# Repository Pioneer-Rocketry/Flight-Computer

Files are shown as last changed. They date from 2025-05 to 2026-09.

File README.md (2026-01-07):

# Pioneer Rocketry Flight Computer

Pioneer Rocketry’s latest generation flight computer for high power, STM32-based avionics system designed for experimental high-power rockets. It provides state estimation, real-time telemetry, staging logic, and fully active control capabilities.
This repository contains the firmware, test tools, and documentation for the system.

---

## Prerequisites

Before building this project, ensure you have the following tools installed and added to your system `PATH`:

1.  **[Visual Studio Code](https://code.visualstudio.com/)** or **[STM32CubeIDE](https://www.st.com/en/development-tools/stm32cubeide.html#get-software)**
2.  **[STM32CubeMX](https://www.st.com/en/development-tools/stm32cubemx.html)** (v6.13 or newer) - Required to generate hardware config.
3.  **Make** Use `winget install ezwinports.make` or `choco install make` - Build system generator.
4.  **[Arm GNU Toolchain](https://developer.arm.com/downloads/-/arm-gnu-toolchain-downloads)** - The compiler (e.g., `arm-none-eabi-gcc`).
5.  **[Ninja Build](https://github.com/ninja-build/ninja/releases)** (Optional) - A faster build system than Make.

### VS Code Extensions
Install the following extensions within VS Code:
* **[Cortex Debug](https://marketplace.visualstudio.com/items?itemName=marus25.cortex-debug)**

---

## Build Instructions

### 1. Clone and Open
Clone the repository and open the folder in VS Code:
```bash
git clone --recurse-submodules https://github.com/Pioneer-Rocketry/Flight-Computer.git
```
### 2. Build the Firmware

You can build the project using the status bar at the bottom or the Command Palette:

* **Status Bar:** Click **Build** (or the generic "Gear" icon).
* **Shortcut:** Press `F7`.

*Successful build output will create a `Code.elf` and `Code.bin` file in the `./Code/build/` directory.*

### 3. Flash and Debug

Connect your STM32 board via ST-Link.

1. Press `F5` to start debugging.
2. The extension will automatically:
* Build the latest code.
* Flash the board using OpenOCD/ST-Link.
* Open the debug console.

### Troubleshooting

* **"Multiple target patterns" error:** Ensure your project folder path contains **NO SPACES** (e.g., use `C:\Dev\Project` instead of `C:\Users\My Name\Project`).
* **C++ vs C:** If `main.cpp` is not being compiled, check `CMakeLists.txt` to ensure `CXX` is enabled and `main.cpp` is listed in the source files. If main.c is in the CDEF, remove it and delete the file.

## Hardware Overview

### **Primary Components**

| Function | Component |
|----|----|
| Main MCU | **STM32F446RE** |
| High-G IMU (Accel + Gyro) | **LSM6DSV32X** |
| Magnetometer | **MMC5603** |
| Barometer | **MS5607-02BA03** |
| GPS | **u-blox SAM-M8Q** |
| Radio | **LoRa SX1262** |

### **Additional Hardware Features**

* 3 independent **pyrotechnic deployment channels**
* Breakouts for **I²C** and **SPI** expansion
* Support for **4 servo channels** (vectoring, control surfaces, etc.)
* USB/Serial connectivity for configuration and simulation
* Ruggedized PCB designed for high-G, high-speed flight

---

## Software Overview

The firmware is written in modern **C++**, using HAL for low-level drivers and a modular class-based architecture for sensors, telemetry, and estimation modules.

### **Key Capabilities**

* **State estimation** for:
  * Attitude (roll, pitch, yaw)
  * Position (x, y, z)
  * Velocity and angular rates
    *(Uses a custom multi-sensor Kalman Filter.)*
* **Live telemetry** over LoRa
* **Event-driven flight logic**, including:
  * Ascent/descent detection
  * Apogee detection
  * Staging and separation logic
  * Deployment sequencing
* **Active Control**
  * Servo-driven stabilization or thrust-vectoring
  * Optional closed-loop controls for advanced tests
* **Fault-tolerant design**
  * Sensor redundancy
  * Fail-safe deployment rules
  * Logging of all states and events

---

## Testing Strategy

### **Hardware-in-the-Loop Testing (HILT)**

HILT allows the flight computer to run full flight software using simulated sensor data.

* The board connects to a PC via USB/Serial.
* A custom simulator streams “fake” IMU, barometer, and GPS data.
* The firmware behaves exactly as if it were in flight.
* Allows testing:
  * Sensor fusion
  * State transitions
  * Staging logic
  * Deployment logic
  * Data logging and telemetry

This framework accelerates development and eliminates many failure modes before field testing.

---

### **Field & Flight Testing**

Flight testing follows a staged, risk-managed approach:

1. **Initial flights:** Validate basic state estimation (position, velocity, attitude) and state transitions.
2. **Intermediate flights:** Add automated apogee deployment, then drogue/main testing, then multistage events.
3. **Advanced flights:**
   * High-speed, high-G tests
   * Full staging logic
   * Active control (servo-active fins or TVC)
   * Redundancy and fault recovery tests

Each successful flight unlocks the next feature set, ensuring safe and repeatable progress toward fully active control.

---

## Repository Structure

```
Flight-Computer/
├── Code/
│   ├── Core/
│   │   ├──Src/
│   │   └── Inc/
│   └── lib/
├── Datasheets/
└── PCB/
```

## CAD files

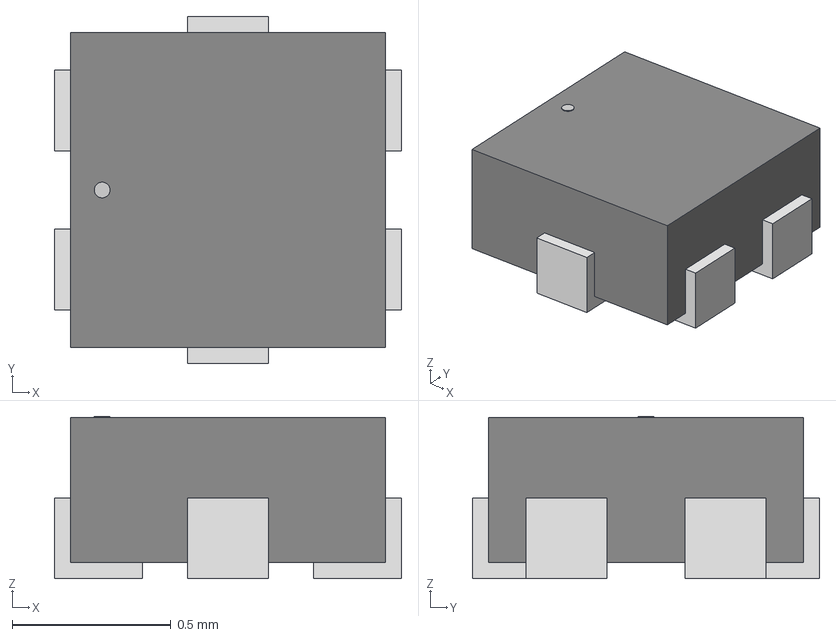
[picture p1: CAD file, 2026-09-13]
PCB/Imported Parts/QFN_453-385LF_SKY.step
1.09 x 1.09 x 0.511 mm

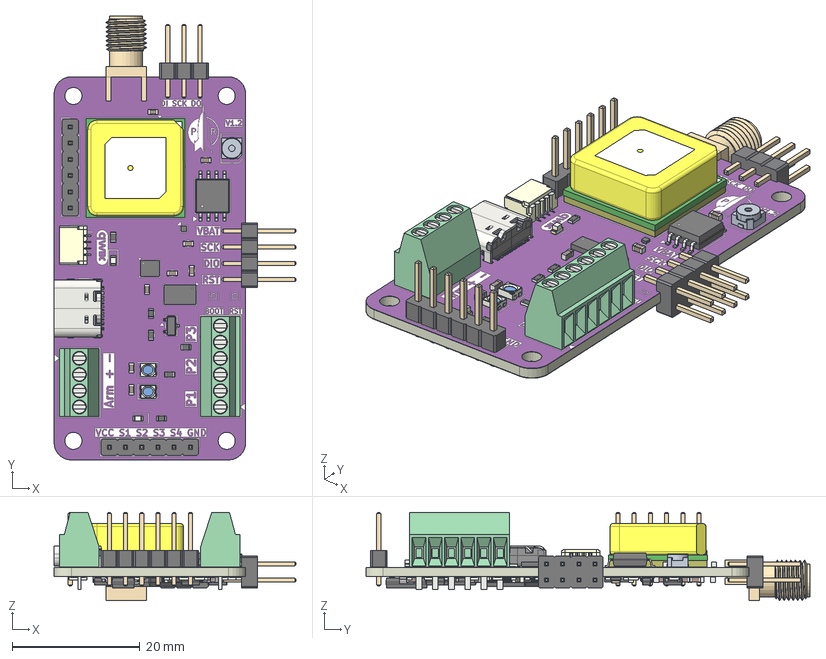
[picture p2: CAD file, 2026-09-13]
PCB/Output/Flight Computer.step
37.9 x 69.5 x 13.8 mm
LED_WS2812B-Mini_PLCC4_3.5x3.5mm_P1.8mm x 2
R_0603_1608Metric x 28
C_0603_1608Metric x 34
WLP-4_0.86x0.86mm_P0.4mm
PinHeader_1x06_P254mm_Vertical x 2
SOT-23-3 x 5
SAM-M8Q-0-10
TerminalBlock_Phoenix_MPT-0,5-4-2.54_1x04_P2.54mm_Horizontal
SM04B-SRSS-TB(LF)(SN)
PinHeader_2x04_P254mm_Vertical
USB_C_Receptacle_16P_TopMnt_Horizontal_GCT_USB4105-xx-A
TerminalBlock_Phoenix_MPT-0,5-6-2.54_1x06_P2.54mm_Horizontal
PRT0002
PRT0008
SOIC-8_5.3x5.3mm_P1.27mm
LGA_14_3x25mm_P05mm_LayoutBorder3x4y
LED_0603_1608Metric x 2
PinHeader_2x03_P254mm_Vertical
LGA_8_3x5mm_P125mm
L_0603_1608Metric x 7
SOT-23 x 2
LQFP-64_10x10mm_P0.5mm
Crystal_SMD_2016-4Pin_2.0x1.6mm
QFN-24-1EP_4x4mm_Pitch0.5mm
SOT-223
SMA_Samtec_SMA-J-P-H-ST-EM1_EdgeMount
CSTNE8M00GH5C000R0
Flight Computer_silkscreen x 2
Flight Computer_soldermask x 2
Flight Computer_PCB

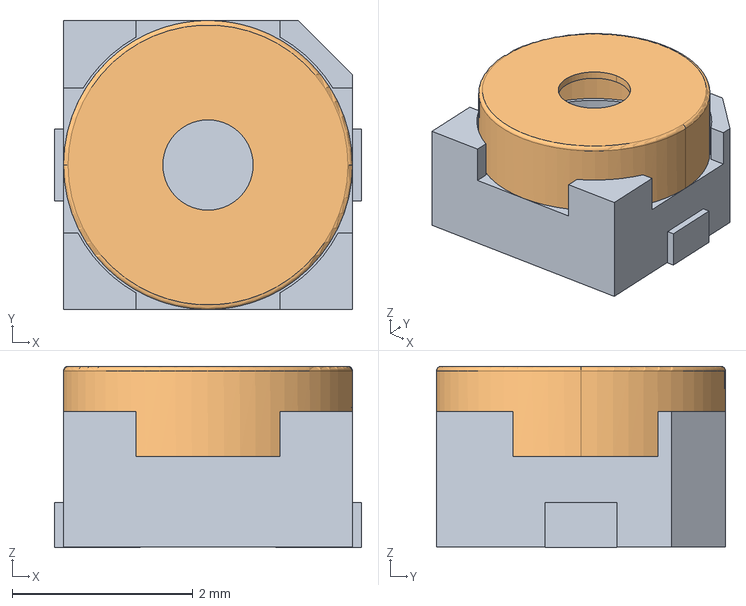
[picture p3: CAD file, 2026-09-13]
PCB/Imported Parts/CT03E-04S400-1_2-2020_062220.stp
3.40 x 3.20 x 2.01 mm
PRT0002
PRT0008

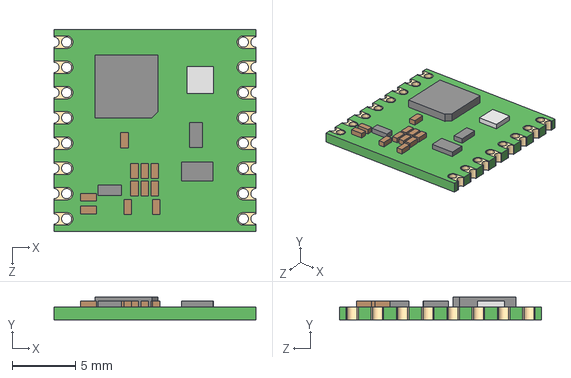
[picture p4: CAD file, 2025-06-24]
PCB/Imported Parts/RFM95W-868S2--3DModel-STEP-56544.STEP
16.0 x 1.80 x 16.0 mm

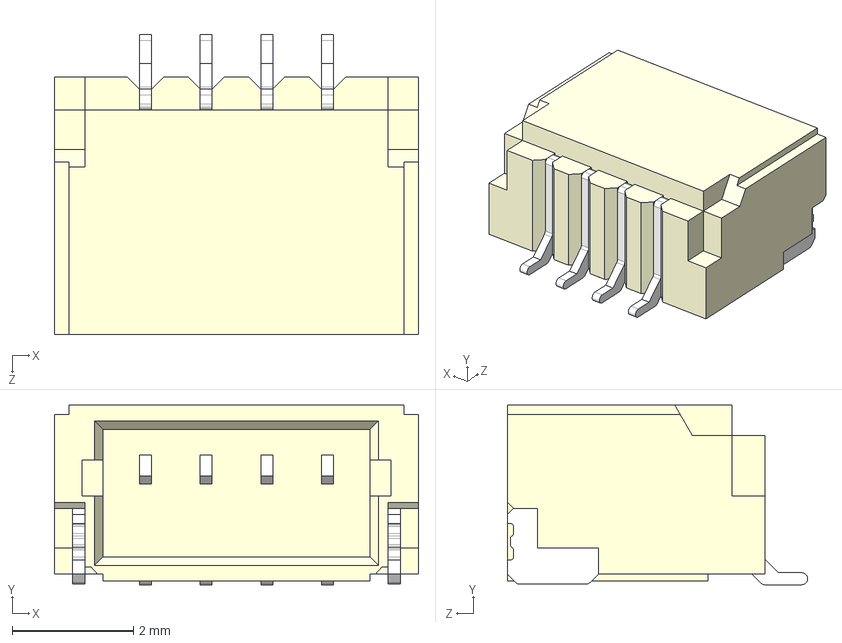
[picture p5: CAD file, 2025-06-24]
PCB/Imported Parts/SM04B-SRSS-TB.STEP
6.00 x 2.96 x 4.95 mm

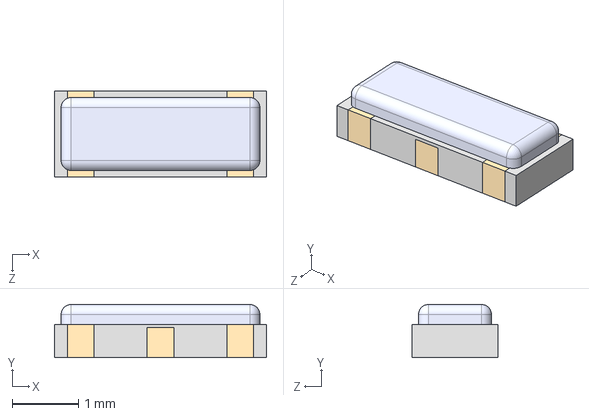
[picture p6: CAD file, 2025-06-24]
PCB/Imported Parts/CSTNE8M00G52Z000R0.STEP
3.20 x 0.8 x 1.30 mm

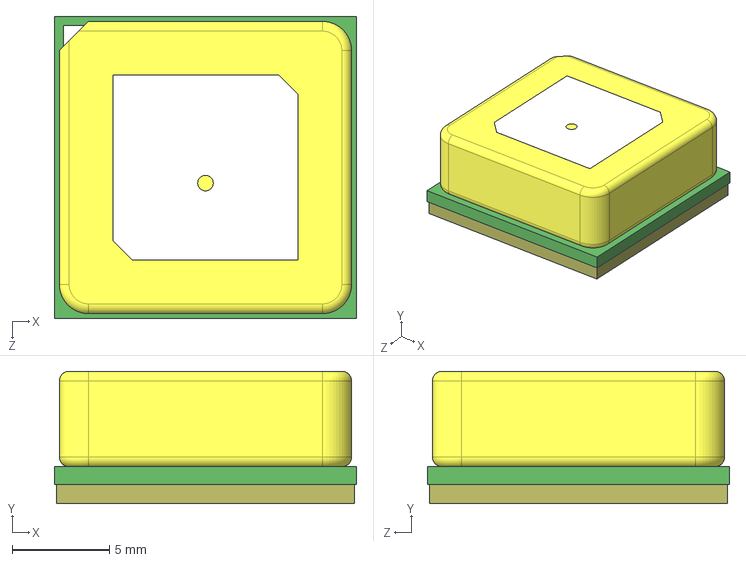
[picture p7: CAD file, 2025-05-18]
PCB/Imported Parts/SAM-M8Q-0.STEP
15.5 x 6.80 x 15.5 mm

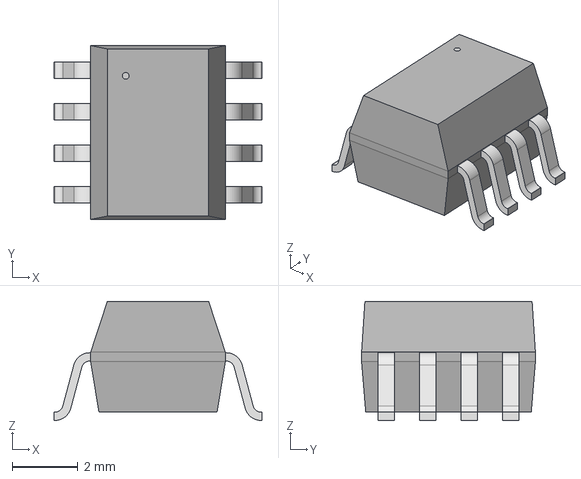
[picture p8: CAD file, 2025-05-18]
PCB/Imported Parts/SOIC-8_VOIH063A_VIS.step
6.35 x 5.31 x 3.63 mm

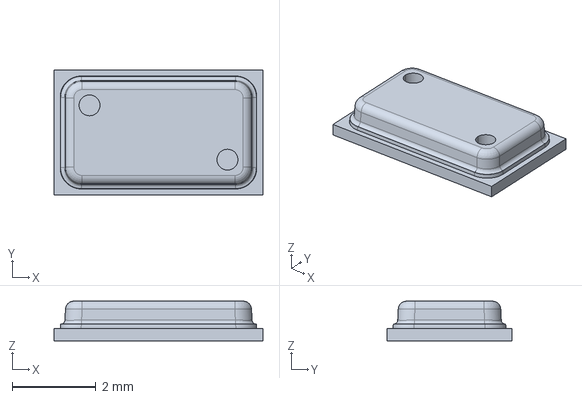
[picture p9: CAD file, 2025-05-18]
PCB/Imported Parts/MS560702BA03-50.STEP
5.00 x 3.00 x 0.95 mm

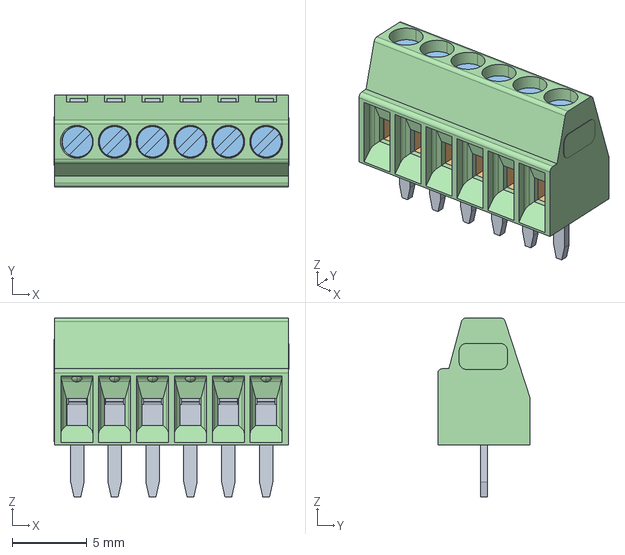
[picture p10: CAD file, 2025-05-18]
PCB/Imported Parts/screw terminal.stp
15.8 x 6.20 x 12.0 mm

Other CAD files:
PCB/Imported Parts/SKY13453.step

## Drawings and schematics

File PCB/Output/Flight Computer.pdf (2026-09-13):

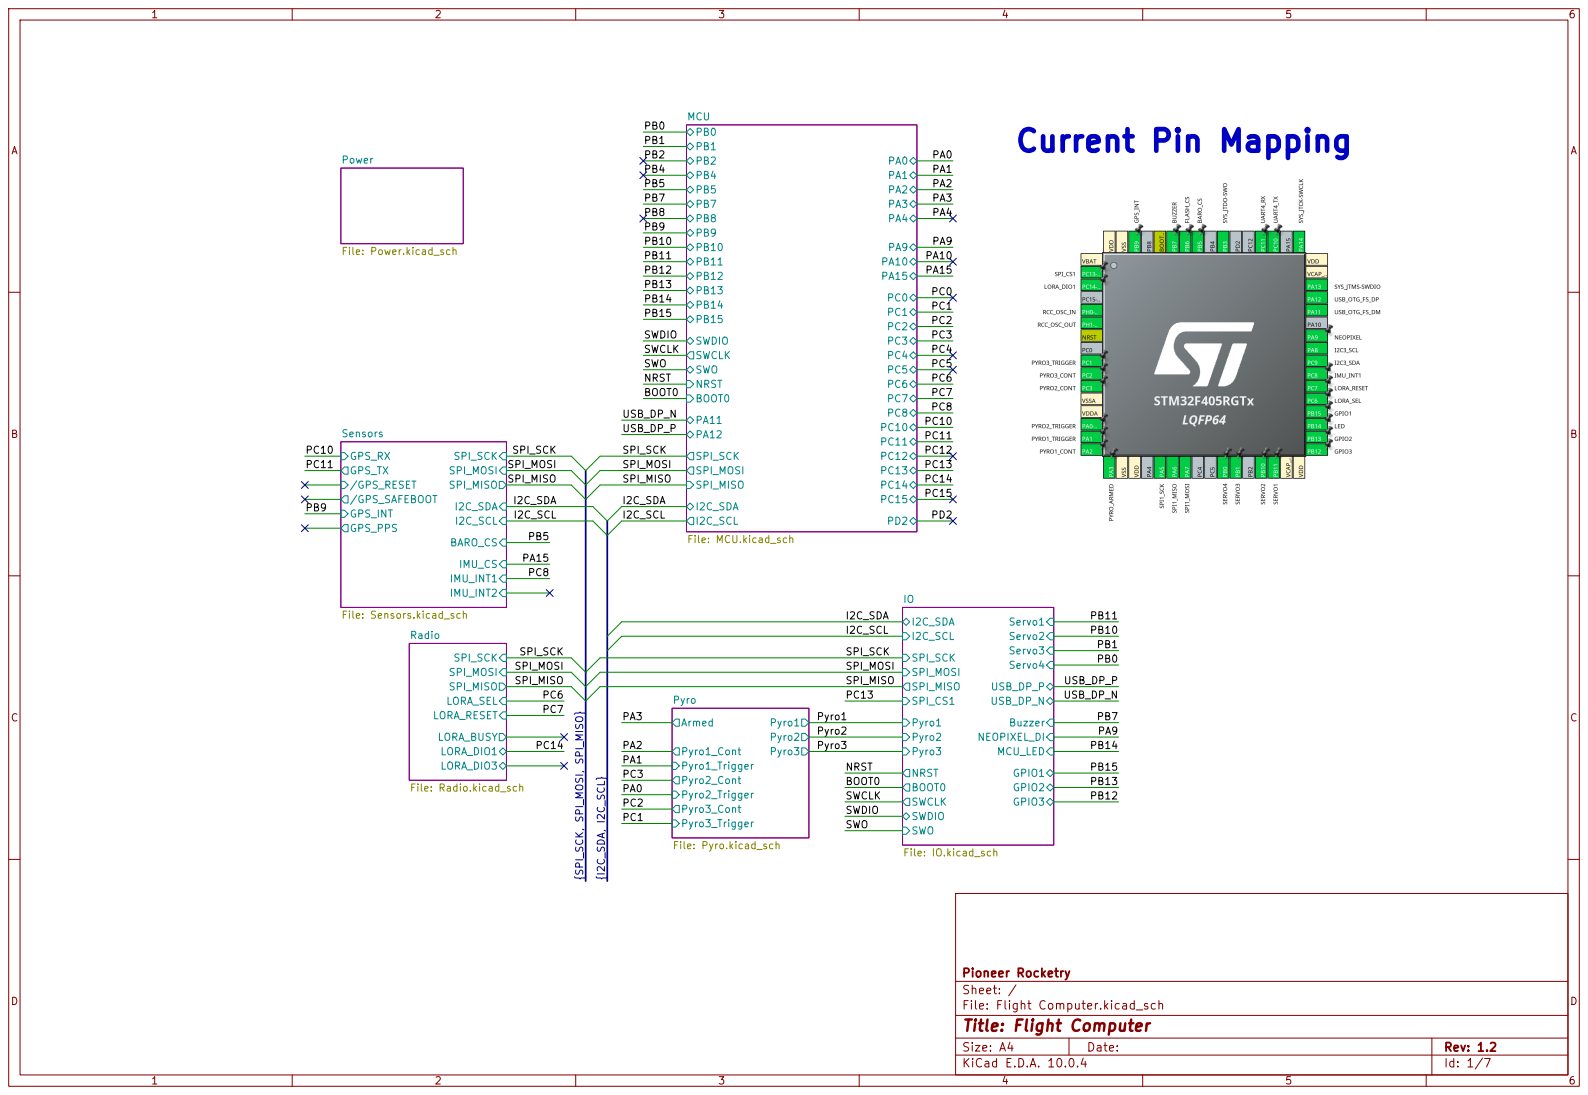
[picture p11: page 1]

File: MCU.kicad_sch Power File: Power.kicad_schSPI_SCK

Size: A4 | Rev: 1.2
KiCad E.D.A. 10.0.4 | Id: 1/7

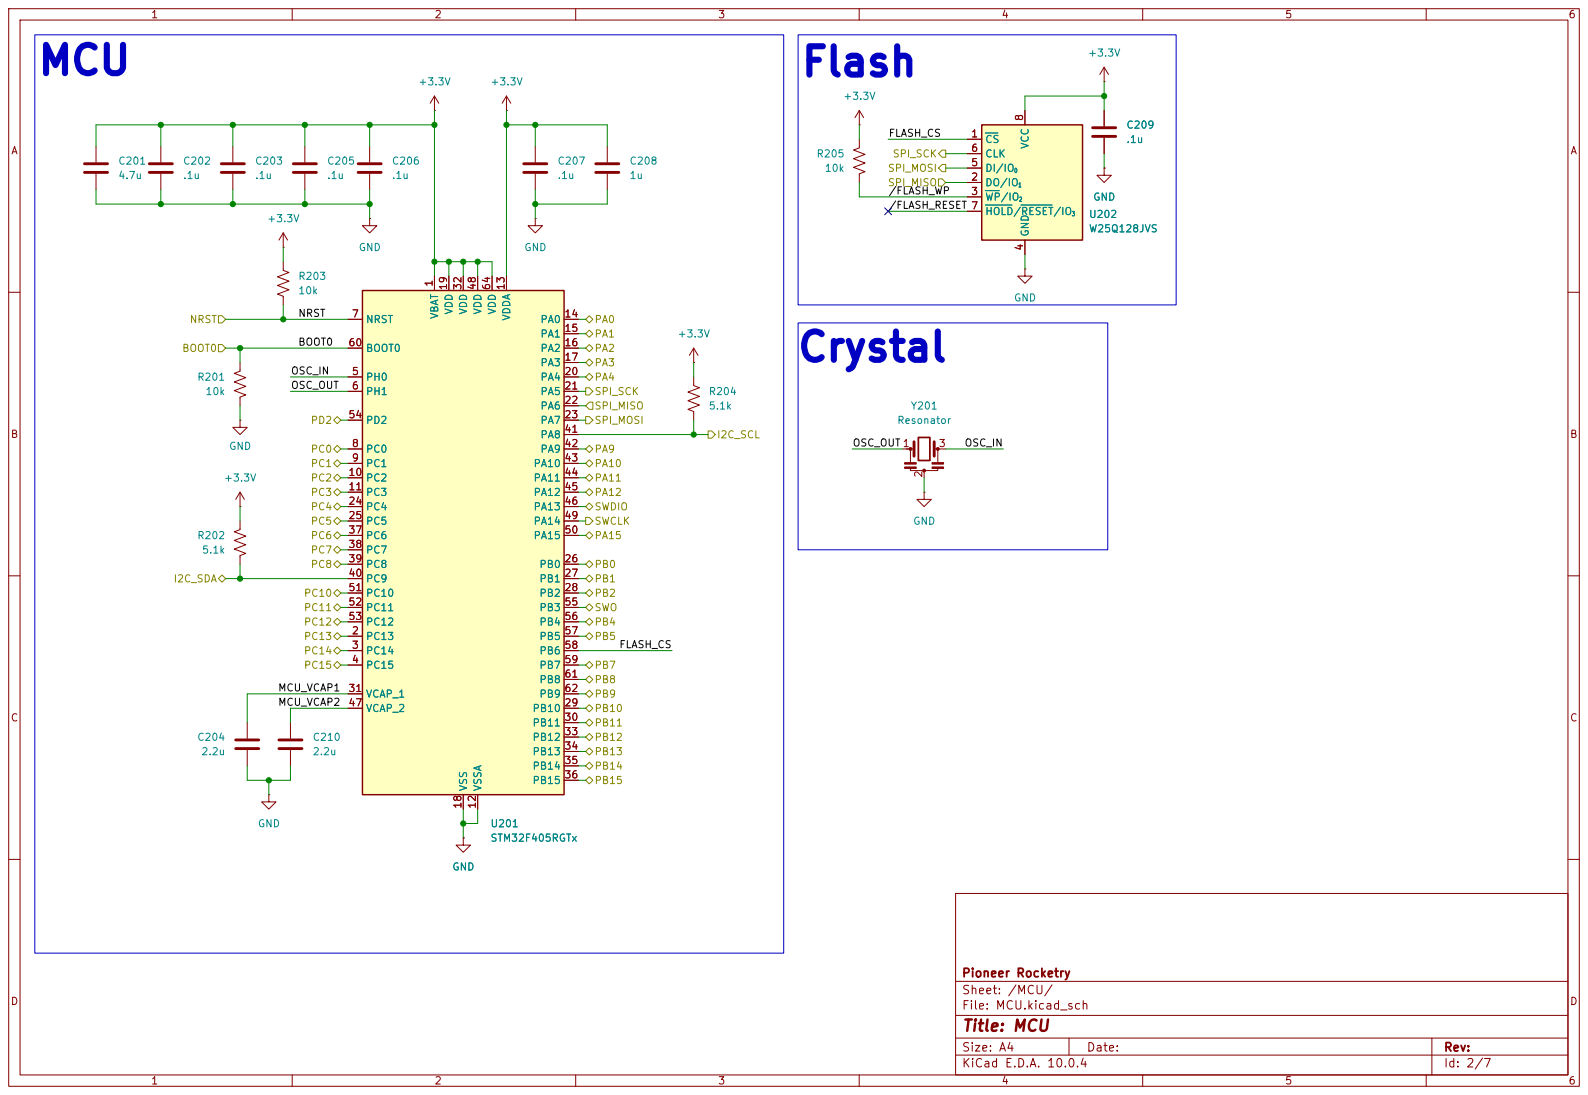
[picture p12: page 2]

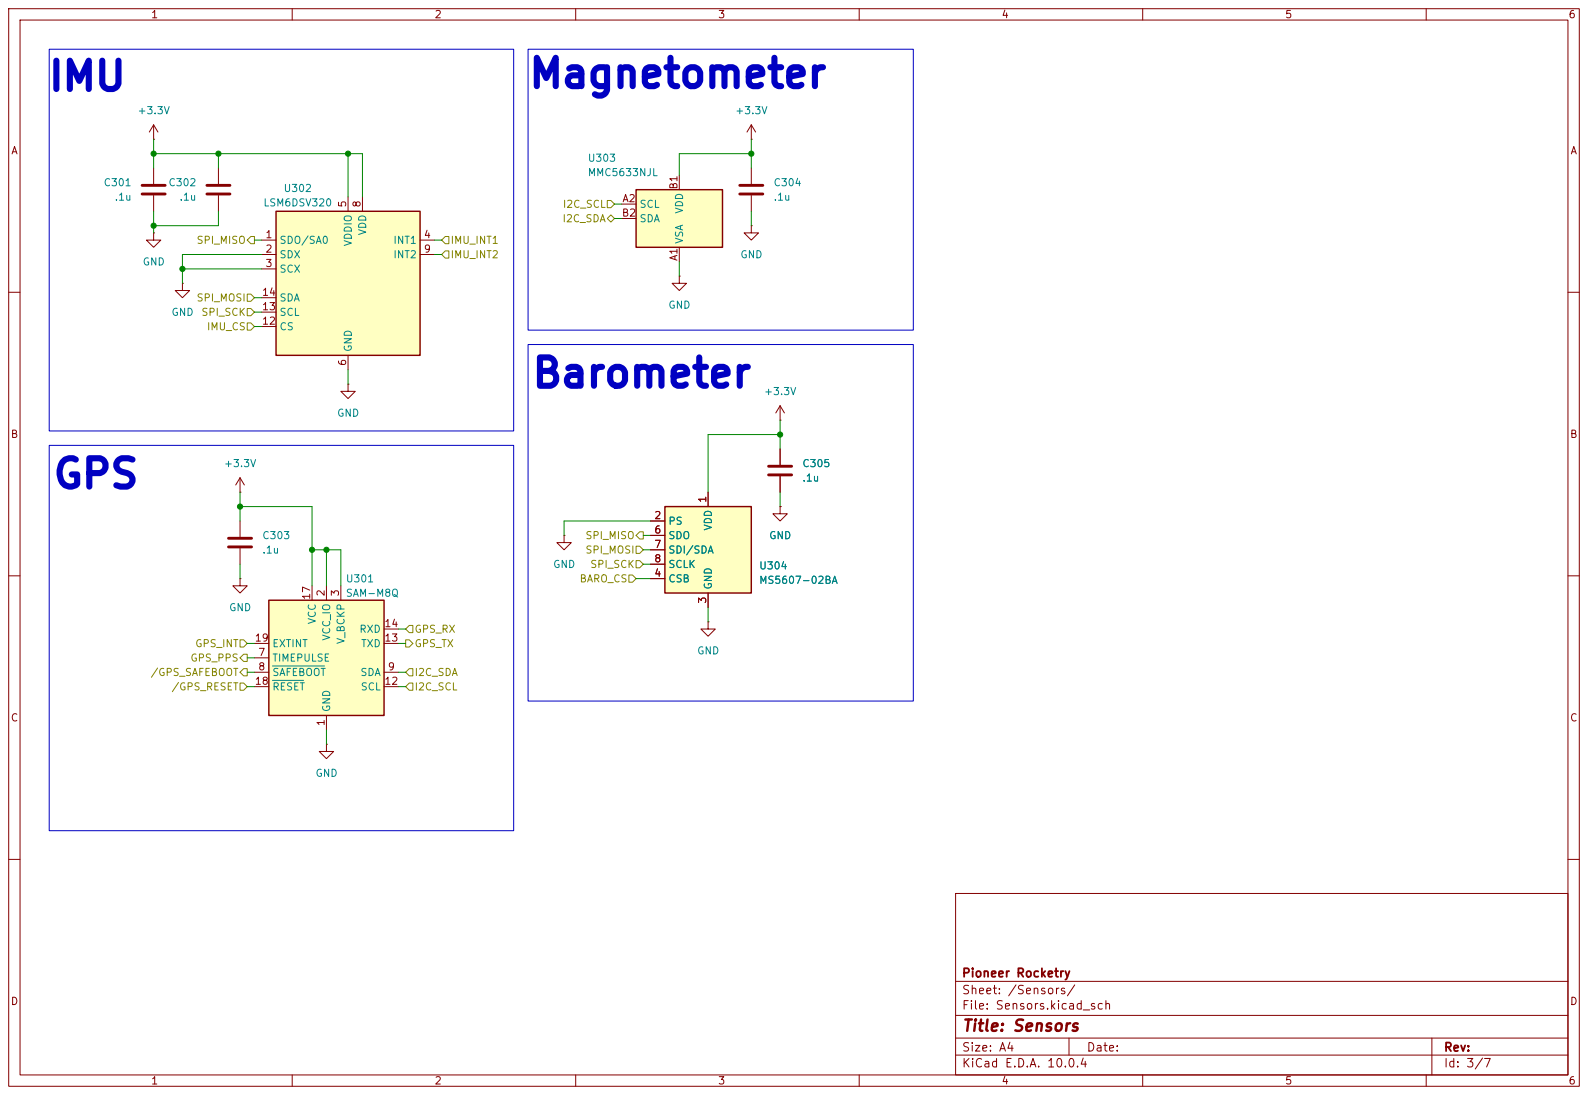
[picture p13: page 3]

TXD 13 RXD 14 VCC 17 RESET 18

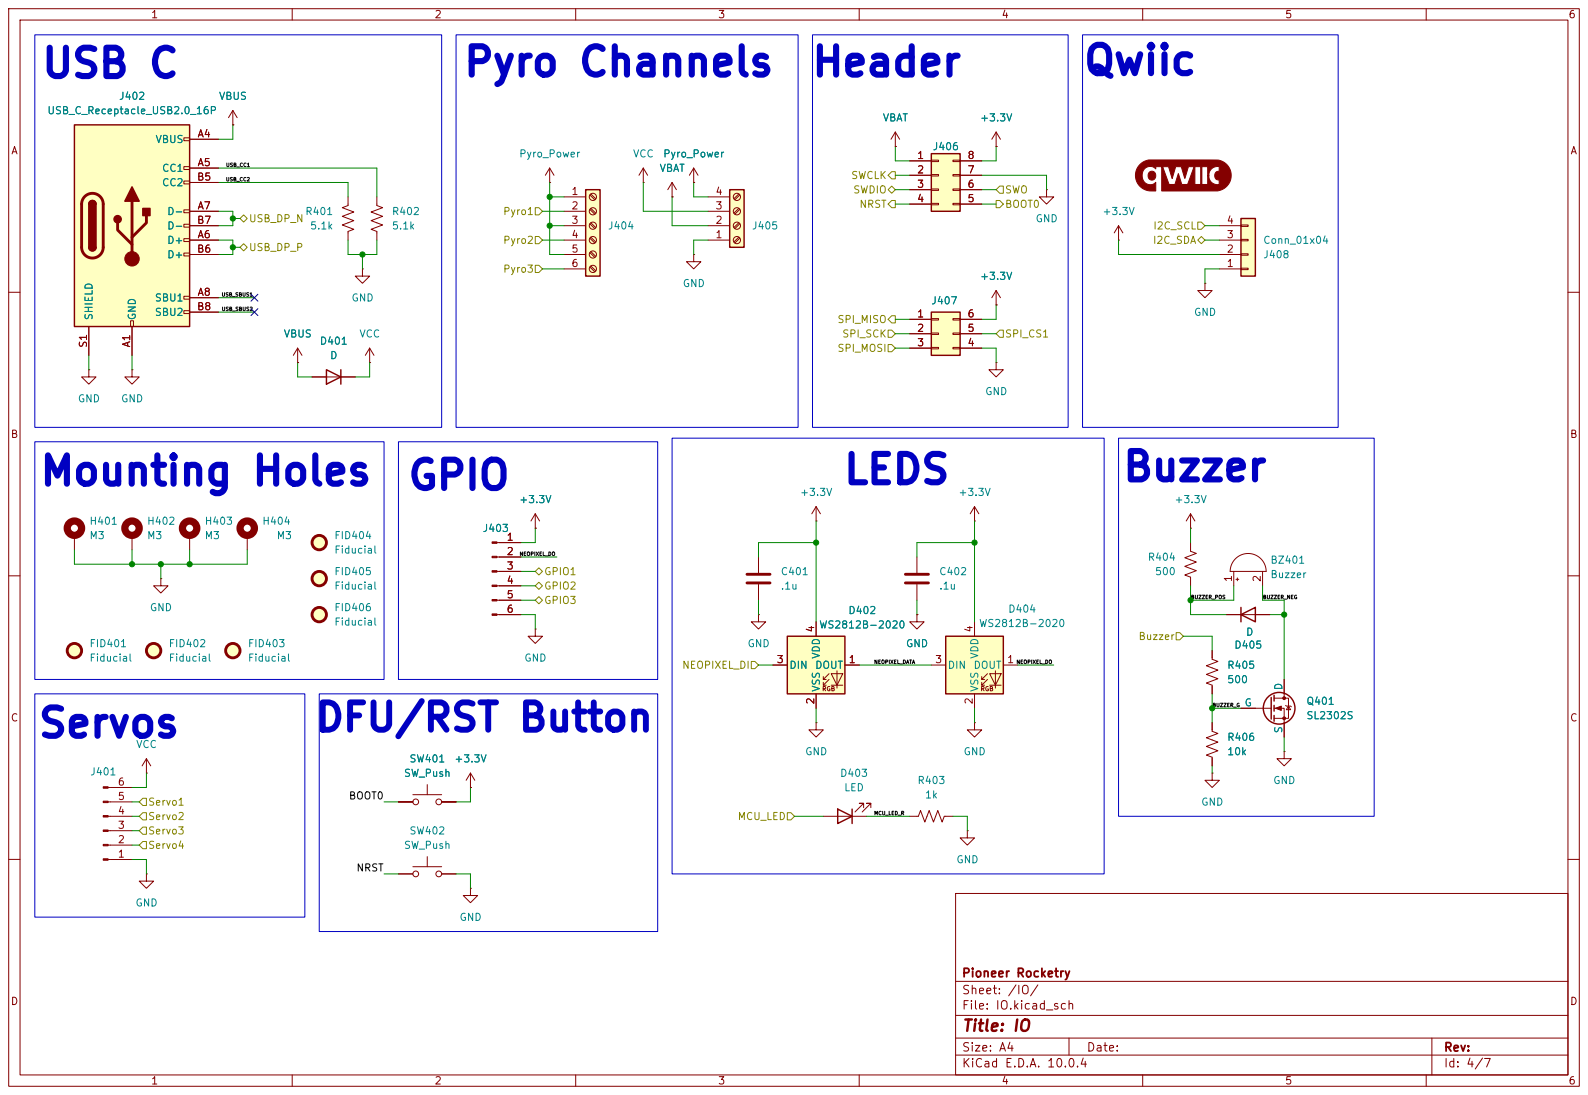
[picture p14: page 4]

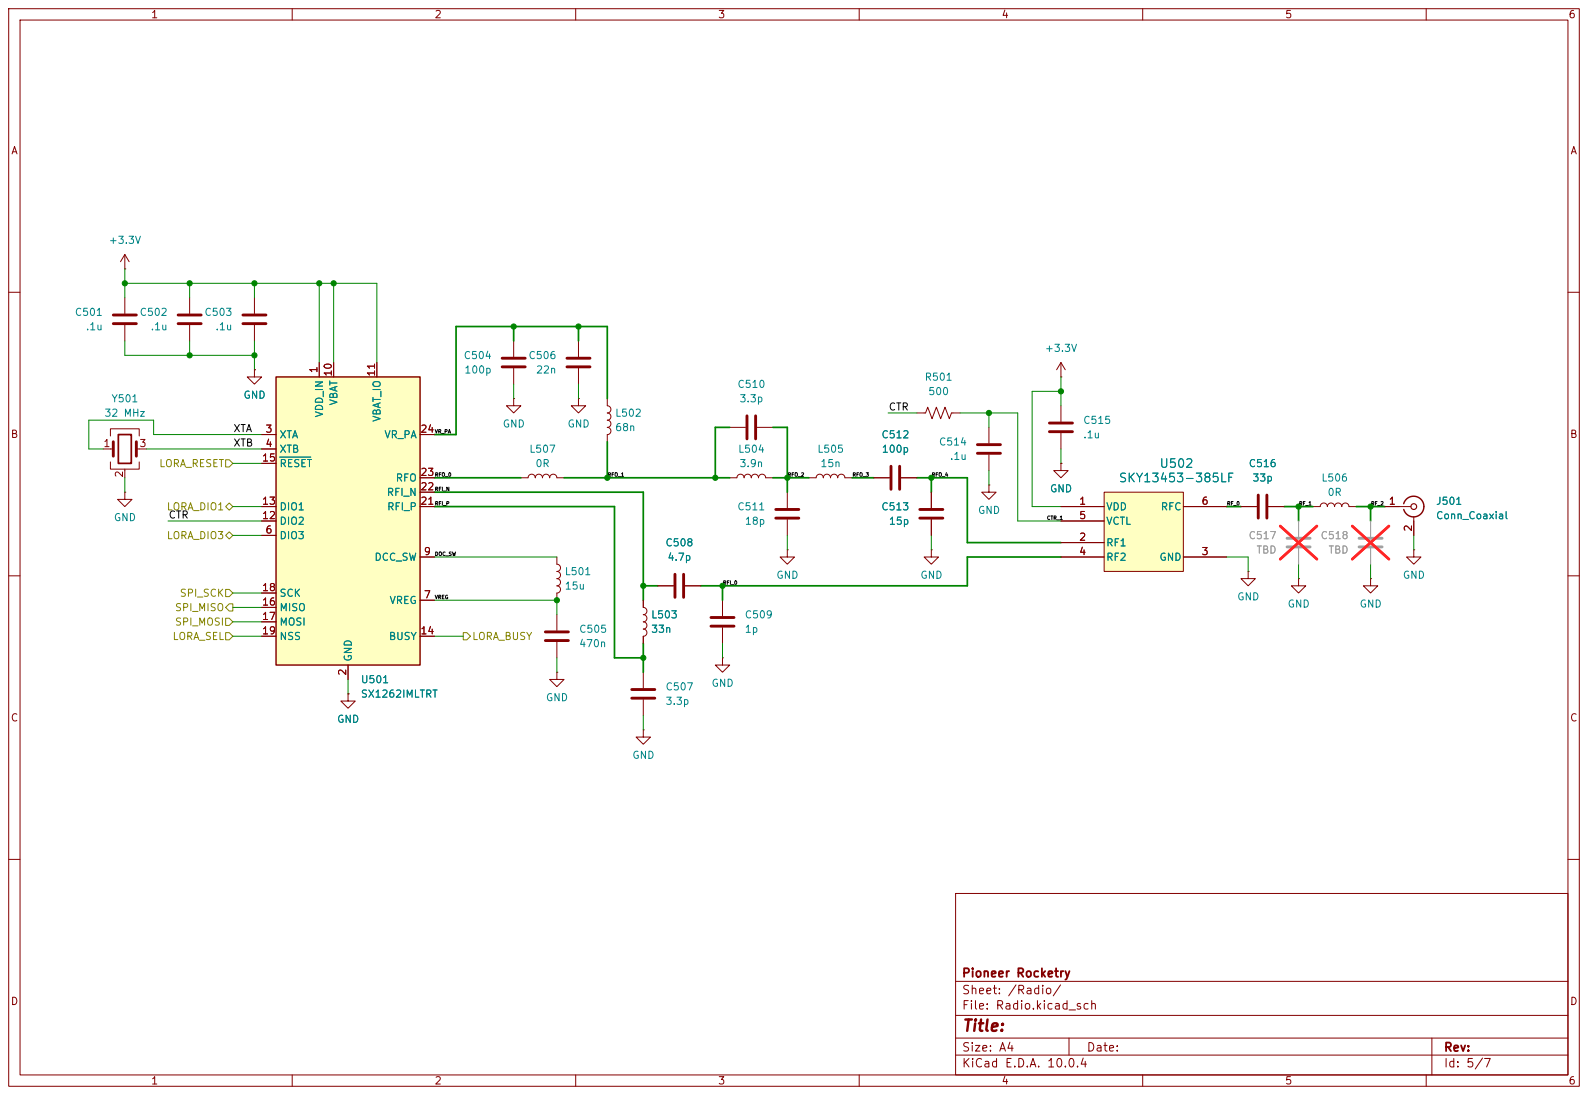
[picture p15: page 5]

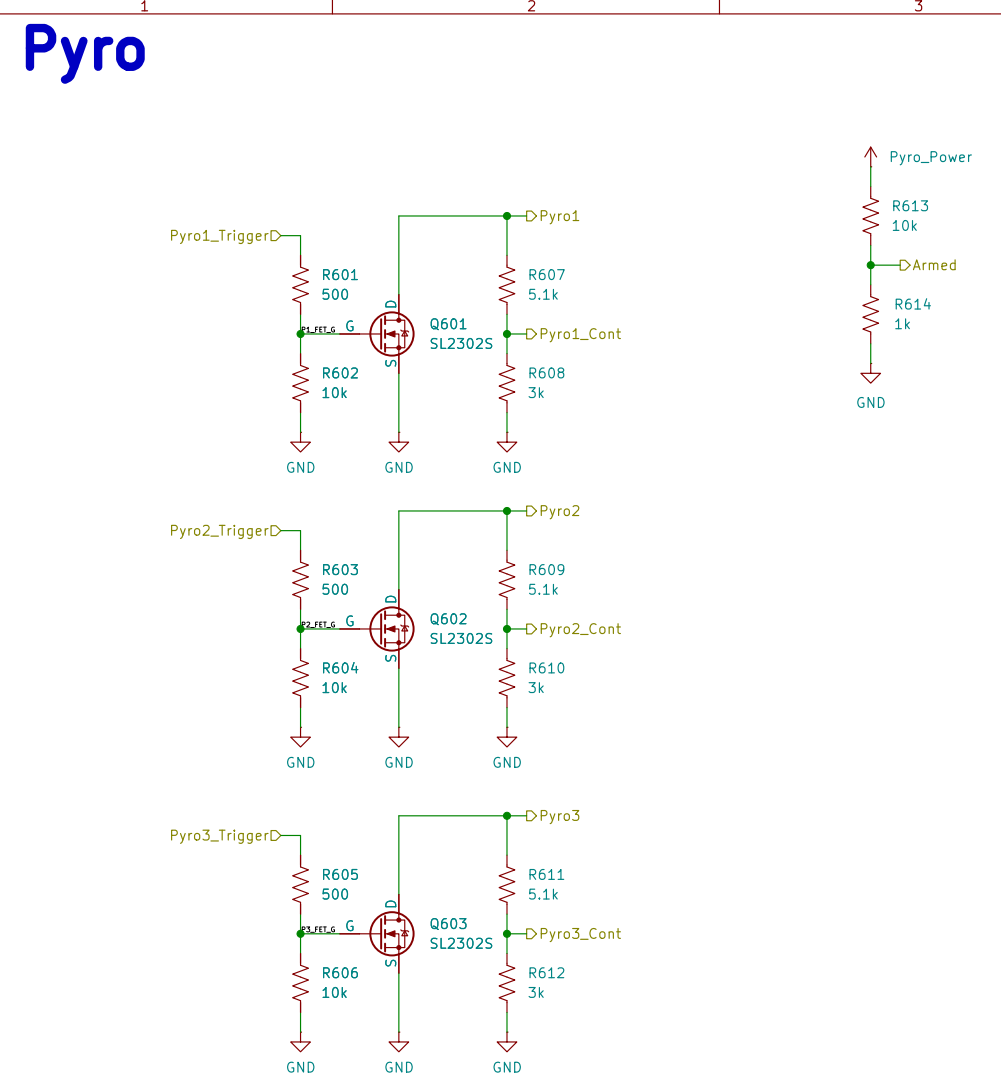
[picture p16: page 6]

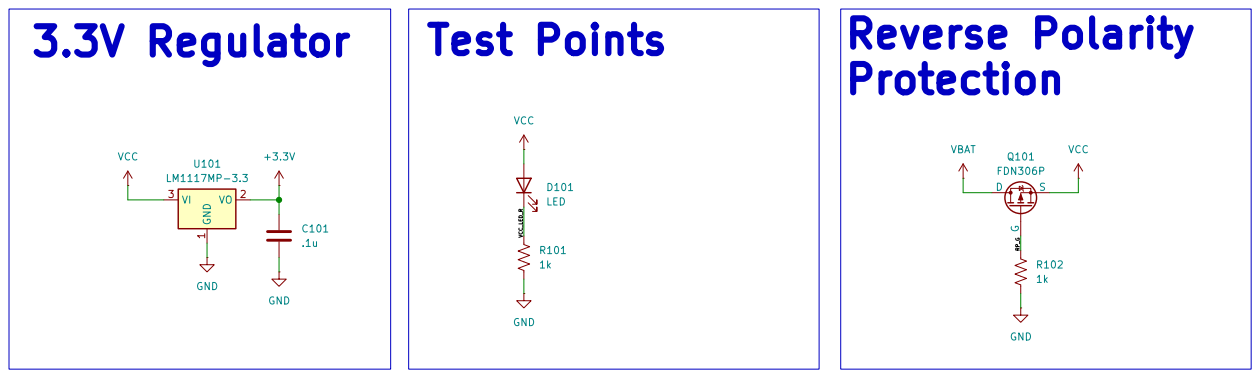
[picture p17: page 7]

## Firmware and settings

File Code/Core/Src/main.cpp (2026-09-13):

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
/* Includes ------------------------------------------------------------------*/
#include "main.h"

/* USER CODE BEGIN Includes */

#include <ctype.h>
#include "tusb.h"
#include "dfuBootloader.h"
#include "usbHelper.h"

#include "DataContainer.h"

/* USER CODE END Includes */

ADC_HandleTypeDef hadc1;

I2C_HandleTypeDef hi2c3;

SPI_HandleTypeDef hspi1;

TIM_HandleTypeDef htim1;
TIM_HandleTypeDef htim2;
TIM_HandleTypeDef htim3;
TIM_HandleTypeDef htim12;

UART_HandleTypeDef huart4;

PCD_HandleTypeDef hpcd_USB_OTG_FS;

extern "C" void SystemClock_Config(void);
static void MX_GPIO_Init(void);
static void MX_ADC1_Init(void);
static void MX_I2C3_Init(void);
static void MX_SPI1_Init(void);
static void MX_TIM1_Init(void);
static void MX_TIM2_Init(void);
static void MX_TIM3_Init(void);
static void MX_TIM12_Init(void);
static void MX_UART4_Init(void);
static void MX_USB_OTG_FS_PCD_Init(void);
/**
  * @brief  The application entry point.
  * @retval int
  */
int main(void)
{

  /* USER CODE BEGIN 1 */

  dfuCheckAndJumpBootloader();

  /* USER CODE END 1 */

  /* MCU Configuration--------------------------------------------------------*/

  /* Reset of all peripherals, Initializes the Flash interface and the Systick. */
  HAL_Init();

  /* Configure the system clock */
  SystemClock_Config();

  /* Initialize all configured peripherals */
  MX_GPIO_Init();
  MX_ADC1_Init();
  MX_I2C3_Init();
  MX_SPI1_Init();
  MX_TIM1_Init();
  MX_TIM2_Init();
  MX_TIM3_Init();
  MX_TIM12_Init();
  MX_UART4_Init();
  MX_USB_OTG_FS_PCD_Init();
  /* USER CODE BEGIN 2 */

  tud_init(BOARD_TUD_RHPORT);

  uint32_t currentTick;
  uint32_t lastSendTick = 0;
  const uint32_t sendIntervalMs = 5000;

  /* USER CODE END 2 */

  /* Infinite loop */
  /* USER CODE BEGIN WHILE */
  while (1)
  {
    /* USER CODE END WHILE */

    /* USER CODE BEGIN 3 */

    tud_task();

    currentTick = HAL_GetTick(); // Get the current system tick (ms)

    // Check if it's time to send data
    if (currentTick - lastSendTick >= sendIntervalMs)
    {
      lastSendTick = currentTick;

      int len = snprintf(usb_tx_buffer, MAX_TICK_MSG_LEN, "Tick: %lu ms\r\n", currentTick);
      cdcSendMessage(usb_tx_buffer, len);
    }
  }
  /* USER CODE END 3 */
}

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
/* USER CODE BEGIN 4 */


void tud_dfu_runtime_reboot_to_dfu_cb(void)
{
  const char* reboot_msg = "Rebooting into DFU mode...\r\n";
  cdcSendMessage(reboot_msg, strlen(reboot_msg));

  // Ensure message is sent
  for (int i = 0; i < 10; i++) {
    tud_task();
    HAL_Delay(5);
  }

  // Request bootloader entry (never returns)
  dfuRequestBootloaderEntry();

}

void tud_dfu_download_cb(uint8_t alt, uint16_t block_num, uint8_t const* data, uint16_t length)
{
  (void)alt;
  (void)block_num;
  (void)data;
  (void)length;

  // This callback is called during the download process
  // We don't need to do anything here since we're using runtime DFU
}

void tud_dfu_manifest_cb(uint8_t alt)
{
  (void)alt;

  // DFU upload complete, reboot back to application
  // Give a short delay to ensure USB transaction completes
  HAL_Delay(100);

  // System reset to return to application
  NVIC_SystemReset();
}


/* USER CODE END 4 */
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


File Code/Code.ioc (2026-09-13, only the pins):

Mcu.UserName=STM32F405RGTx
PA0-WKUP.GPIO_Label=PYRO2_TRIGGER
PA0-WKUP.Signal=GPIO_Output
PA1.GPIO_Label=PYRO1_TRIGGER
PA1.Signal=GPIO_Output
PA11.Signal=USB_OTG_FS_DM
PA12.Signal=USB_OTG_FS_DP
PA13.Signal=SYS_JTMS-SWDIO
PA14.Signal=SYS_JTCK-SWCLK
PA2.GPIO_Label=PYRO1_CONT
PA2.Signal=ADCx_IN2
PA3.GPIO_Label=PYRO_ARMED
PA3.Signal=ADCx_IN3
PA5.Signal=SPI1_SCK
PA6.Signal=SPI1_MISO
PA7.Signal=SPI1_MOSI
PA8.Signal=I2C3_SCL
PA9.GPIO_Label=NEOPIXEL
PA9.Signal=S_TIM1_CH2
PB0.GPIO_Label=SERVO4
PB0.Signal=S_TIM3_CH3
PB1.GPIO_Label=SERVO3
PB1.Signal=S_TIM3_CH4
PB10.GPIO_Label=SERVO2
PB10.Signal=S_TIM2_CH3
PB11.GPIO_Label=SERVO1
PB11.Signal=S_TIM2_CH4
PB12.GPIO_Label=GPIO3
PB12.Signal=GPIO_Output
PB13.GPIO_Label=GPIO2
PB13.Signal=GPIO_Output
PB14.GPIO_Label=LED
PB14.Signal=S_TIM12_CH1
PB15.GPIO_Label=GPIO1
PB15.Signal=GPIO_Output
PB3.Signal=SYS_JTDO-SWO
PB5.GPIO_Label=BARO_CS
PB5.Signal=GPIO_Output
PB6.GPIO_Label=FLASH_CS
PB6.Signal=GPIO_Output
PB7.GPIO_Label=FLASH_RESET
PB7.Signal=GPIO_Output
PB9.GPIO_Label=GPS_INT
PB9.Signal=GPXTI9
PC1.GPIO_Label=PYRO3_TRIGGER
PC1.Signal=GPIO_Output
PC10.Signal=UART4_TX
PC11.Signal=UART4_RX
PC13-ANTI_TAMP.GPIO_Label=SPI_CS1
PC13-ANTI_TAMP.Signal=GPIO_Output
PC14-OSC32_IN.GPIO_Label=LORA_DIO0
PC14-OSC32_IN.Signal=GPIO_Output
PC2.GPIO_Label=PYRO3_CONT
PC2.Signal=ADCx_IN12
PC3.GPIO_Label=PYRO2_CONT
PC3.Signal=ADCx_IN13
PC6.GPIO_Label=LORA_SEL
PC6.Signal=GPIO_Output
PC7.GPIO_Label=LORA_RESET
PC7.Signal=GPIO_Output
PC8.GPIO_Label=IMU_INT1
PC8.Signal=GPXTI8
PC9.Signal=I2C3_SDA
PH0-OSC_IN.Signal=RCC_OSC_IN
PH1-OSC_OUT.Signal=RCC_OSC_OUT

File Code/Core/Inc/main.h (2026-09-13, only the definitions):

#define SPI_CS1_Pin GPIO_PIN_13
#define SPI_CS1_GPIO_Port GPIOC
#define LORA_DIO0_Pin GPIO_PIN_14
#define LORA_DIO0_GPIO_Port GPIOC
#define PYRO3_TRIGGER_Pin GPIO_PIN_1
#define PYRO3_TRIGGER_GPIO_Port GPIOC
#define PYRO3_CONT_Pin GPIO_PIN_2
#define PYRO3_CONT_GPIO_Port GPIOC
#define PYRO2_CONT_Pin GPIO_PIN_3
#define PYRO2_CONT_GPIO_Port GPIOC
#define PYRO2_TRIGGER_Pin GPIO_PIN_0
#define PYRO2_TRIGGER_GPIO_Port GPIOA
#define PYRO1_TRIGGER_Pin GPIO_PIN_1
#define PYRO1_TRIGGER_GPIO_Port GPIOA
#define PYRO1_CONT_Pin GPIO_PIN_2
#define PYRO1_CONT_GPIO_Port GPIOA
#define PYRO_ARMED_Pin GPIO_PIN_3
#define PYRO_ARMED_GPIO_Port GPIOA
#define SERVO4_Pin GPIO_PIN_0
#define SERVO4_GPIO_Port GPIOB
#define SERVO3_Pin GPIO_PIN_1
#define SERVO3_GPIO_Port GPIOB
#define SERVO2_Pin GPIO_PIN_10
#define SERVO2_GPIO_Port GPIOB
#define SERVO1_Pin GPIO_PIN_11
#define SERVO1_GPIO_Port GPIOB
#define GPIO3_Pin GPIO_PIN_12
#define GPIO3_GPIO_Port GPIOB
#define GPIO2_Pin GPIO_PIN_13
#define GPIO2_GPIO_Port GPIOB
#define LED_Pin GPIO_PIN_14
#define LED_GPIO_Port GPIOB
#define GPIO1_Pin GPIO_PIN_15
#define GPIO1_GPIO_Port GPIOB
#define LORA_SEL_Pin GPIO_PIN_6
#define LORA_SEL_GPIO_Port GPIOC
#define LORA_RESET_Pin GPIO_PIN_7
#define LORA_RESET_GPIO_Port GPIOC
#define IMU_INT1_Pin GPIO_PIN_8
#define IMU_INT1_GPIO_Port GPIOC
#define NEOPIXEL_Pin GPIO_PIN_9
#define NEOPIXEL_GPIO_Port GPIOA
#define BARO_CS_Pin GPIO_PIN_5
#define BARO_CS_GPIO_Port GPIOB
#define FLASH_CS_Pin GPIO_PIN_6
#define FLASH_CS_GPIO_Port GPIOB
#define FLASH_RESET_Pin GPIO_PIN_7
#define FLASH_RESET_GPIO_Port GPIOB
#define GPS_INT_Pin GPIO_PIN_9
#define GPS_INT_GPIO_Port GPIOB

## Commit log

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2025-05-21 Finished 1 iteration of the Flight Computer
    [Flight Computer v3 - Kicad.kicad_sch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]
2025-05-22 Fixed small PCB problems, and setup build env
    [Flight Computer v3.kicad_pcb, Flight Computer v3.kicad_sch, MCU.kicad_sch]
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2025-05-23 Fixed indentation for main.cpp Added imu begin to main
    [main.cpp]
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2025-05-27 Fixed register mapping name
    [imu_LSM6DSV320.h]
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2025-05-30 Moved i2c to different set of pins
    [Flight Computer v3.kicad_pcb, MCU.kicad_sch, Sensors.kicad_sch]
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2025-05-30 set the correct loop rate
    [main.cpp]
2025-05-30 fixed imu not pulling low G data
    [imu_LSM6DSV320.cpp]
2025-05-31 Made and testing barometer driver, in process broke the Hz counter
    [baro_MS5607.cpp, main.cpp]
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2025-06-01 Renamed MCUViewer_Config -> MCUViewer_Config.cfg
    [MCUViewer_Config.cfg]
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2025-06-02 Modified MCU Viewer to have multiply groups 1 for raw data, 1 for state estimation
    [MCUViewer_Config.cfg]
2025-06-02 renamed file output from Flight-Computer-v3 to Flight-Computer
    [MCUViewer_Config.cfg]
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2025-06-04 Modified read_SPI to handle multiply bytes
    [MCUViewer_Config.cfg]
2025-06-05 renamed get_data to loop, and made state_machine call i2c/spi device loop
    [MCUViewer_Config.cfg]
2025-06-05 Made sensors use SPI instead of I2C Change external I2C connector to qwiic Made SWD have its own pin header
    [Flight Computer v3-B_Cu.gbr, Flight Computer v3-B_Mask.gbr, Flight Computer v3-B_Paste.gbr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]
2025-06-05 put sensors in the correct odrs
    [imu_LSM6DSV320.h, main.cpp]
2025-06-05 Enabled filters for accelometers and gyros for less noise
    [imu_LSM6DSV320.cpp, imu_LSM6DSV320.h]
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2025-06-06 fixed the orientation jumping around when freq isnt 100% consistant
    [main.cpp]
2025-06-07 Removed unneeded getters/setters cause the vars are public Orientation filter is closer to correct
    [imu_LSM6DSV320.cpp, mag_MMC5603NJ.cpp]
2025-06-07 Added vector for accel in earth refrence frame
    [MCUViewer_Config.cfg]
2025-06-08 Created basic flash driver, should be able to write data to flash, and print out the data
    [MCUViewer_Config.cfg]
2025-06-09 Renamed PCB files to remove v3 from the names
    [Flight Computer.kicad_pcb, Flight Computer.kicad_sch, IO.kicad_sch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]
2025-06-09 modified schematic a bit to look nicer
    [Sensors.kicad_sch]
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2025-06-11 Created Bill of materials for the computer
    [BOM.xlsx, Flight Computer.csv, IO.kicad_sch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]
2025-06-24 Cleaned up the schematic and replace and rerouted everything, also replace radio with a module
    [CSTNE8M00G52Z000R0.STEP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]
2025-06-24 Updated BOM Added logo to PCB Reexported schematic
    [BOM.xlsx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]
2025-06-24 Fixed barometer wiring
    [Flight Computer.kicad_pcb, Flight Computer.kicad_sch, MCU.kicad_sch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]
2025-06-24 Updated BOM and fixed all ERC and DRC errors
    [BOM.xlsx, Flight Computer.csv, Flight Computer.kicad_pcb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]
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2025-06-24 Fixed SWD pinout Updated CubeMX Project
    [Flight Computer.kicad_pcb, Flight Computer.kicad_sch, IO.kicad_sch]
2025-06-25 Redid layout to make it look a little nicer Added some silkscreen to connectors
    [Flight Computer-B_Cu.gbr, Flight Computer-B_Mask.gbr, Flight Computer-B_Paste.gbr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]
2025-06-25 Fixed Pioneer Rocketry Logo
    [Flight Computer-B_Cu.gbr, Flight Computer-B_Mask.gbr, Flight Computer-B_Paste.gbr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]
2025-06-25 Updated 3D model Removed extra silkscreen text
    [Flight Computer-B_Cu.gbr, Flight Computer-B_Mask.gbr, Flight Computer-B_Paste.gbr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]
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2025-07-04 Renamed nets from pryo to pyro cause I can't spell
    [Flight Computer.kicad_pcb, Flight Computer.kicad_sch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]
2025-07-15 Fixed pricing
    [BOM.xlsx]
2025-07-16 Did design review, just need to debug pyro channel
    Changed pull resistor on the pyro channel from 1k to 10k during design review
    [BOM.xlsx, Pyro.kicad_sch]
2025-07-17 Flipped MOSI and MISO on the IMU
    Updated all output files for the PCB
    [Flight Computer-B_Cu.gbr, Flight Computer-B_Mask.gbr, Flight Computer-B_Paste.gbr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]
2025-08-17 Cleaned up schematic Change from SPI and I2C to busses
    [BOM.xlsx, Flight Computer.kicad_pcb, Flight Computer.kicad_sch]
2025-08-20 Update Barometer SPI connection
    [Flight Computer.kicad_pcb, Flight Computer.kicad_sch, Sensors.kicad_sch]
2025-09-05 Switch from high side switch to low side switch for pyro channels
    [Flight Computer.kicad_pcb, IO.kicad_sch, MCU.kicad_sch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]
2025-09-05 Fixed component annotation Updated BOM to reflect the pyro channel changes Updates Production files
    [BOM.xlsx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]
2025-10-11 Switched from VSCode to STM32CubeIDE
    [MCUViewer_Config.cfg]
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2025-11-25 Added basic buzzer, LED, and fiducials to the schematic
    [Flight Computer.kicad_sch, IO.kicad_sch, MCU.kicad_sch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]
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2025-12-24 Removed files from .gitigore
    [Flight Computer-B_Cu.gbr, Flight Computer-B_Mask.gbr, Flight Computer-B_Paste.gbr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]
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2026-01-09 - Updated schematic with solutions to the hardware problems - Remove files that are the .gitignore
    [Flight Computer.kicad_pcb, IO.kicad_sch, MCU.kicad_sch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]
2026-01-28 Added buzzer Added 2 more leds to MCU Fixed servo connector GND hole shape Added Servo VCC pin Added additional silkscreen for debug connections Added copper plane text "V1.1" Made 915MHz radio trace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
    [CT03E-04S400-1_2-2020_062220.stp, Flight Computer.kicad_pcb, IO.kicad_sch]
2026-01-28 Fixed some mistakes
    [Flight Computer.kicad_pcb, IO.kicad_sch]
2026-02-02 Switched MISO and MOSI for IMU, fixed some DRC Errors
    [Flight Computer.kicad_pcb, Sensors.kicad_sch]
2026-02-02 Tweaked silkscreen, update via count for 3.3V reg VCC trace
    [Flight Computer.kicad_pcb]
2026-02-05 Moved compass away from power traces, minor routing changes
    [Flight Computer.kicad_pcb, Flight Computer.kicad_sch, IO.kicad_sch]
2026-02-05 Moved magnetometer slightly, updated routing more
    [Flight Computer.kicad_pcb]
2026-02-05 Added more GND vias around mosfets for pyro channels
    [Flight Computer.kicad_pcb]
2026-02-05 added resistor value to buzzer current limiting resistor
    [IO.kicad_sch]
2026-02-06 Finalized buzzer footprint and minor tweaks
    [Flight Computer.kicad_pcb]
2026-02-20 Added DFU button and VCC pad by programming header
    [Flight Computer.kicad_pcb, IO.kicad_sch]
2026-02-21 DRC Fixes
    [Flight Computer.kicad_pcb]
2026-02-22 Added two more GPIO test pads
    [Flight Computer.kicad_pcb, Flight Computer.kicad_sch, IO.kicad_sch]
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2026-05-30 Replaced the radio in the schematic
    [Flight Computer.kicad_sch, IO.kicad_sch, MCU.kicad_sch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]
2026-06-06 - Swapped out 2 LED's for neopixels- Added reverse polarity protection- Replaced Radio module with deticated IC and passives
    [Flight Computer.kicad_sch, IO.kicad_sch, MCU.kicad_sch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]
2026-06-06 Updated PCB to have the new parts (unrouted)
    [Flight Computer.kicad_pcb, IO.kicad_sch, Radio.kicad_sch]
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2026-06-07 Changed pin mappings a tad. Added courtyards to some parts that were missing them
    [Flight Computer.kicad_pcb, Flight Computer.kicad_sch]
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2026-06-07 Added logo to project files. Added courtyard to logo. Added Componet Pos to jobset
    [Flight Computer-B_Cu.gbl, Flight Computer-B_Mask.gbs, Flight Computer-B_Paste.gbp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]
2026-06-10 - Renamed all NETs connected to MCU sheet to the pin name - Cleaned up schematic - Named all unnamed NETs
    [Flight Computer-B_Cu.gbl, Flight Computer-B_Mask.gbs, Flight Computer-B_Paste.gbp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]
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2026-07-11 Added power pins to the programming header. Moved NeoPixels out location to the GPIO header Reran build job
    [Flight Computer-B_Cu.gbl, Flight Computer-B_Mask.gbs, Flight Computer-B_Paste.gbp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]
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2026-07-11 Used KiCad's annotation tool to reannotate some of the parts Updated BOM
    [BOM.xlsx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]
2026-07-11 Made it so USB isn't putting 4.7v into the battery
    [Flight Computer-B_Cu.gbl, Flight Computer-B_Mask.gbs, Flight Computer-B_Paste.gbp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]
2026-07-11 Made sure all part numbers were for the tape version of the part Added notes for parts that are out of stock
    [BOM.xlsx]
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2026-07-12 Create github action to run kicad jobset and push the output files
    [Flight Computer.kicad_pcb]
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2026-07-12 Added an image of the pin mapping from cubemx to the schematic
    [Flight Computer.kicad_pcb, Flight Computer.kicad_sch]
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2026-07-13 swapped power and gnd on the servo header
    [Flight Computer.kicad_pcb, IO.kicad_sch]
2026-09-11 - Added missing inductor to make it work with 915 Mhz - Added digikey part number as a property - Reran jobset - Removed out of date BOM.xlsx - Attempted to use the config addon (didn't fully work)
    [BOM.xlsx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]
2026-09-12 - Got the extension KiVar working to switch between a 433MHz and 915MHz radio - Added Digikey-PN's for the 915 MHz radio
    [Flight Computer-B_Cu.gbl, Flight Computer-B_Mask.gbs, Flight Computer-B_Paste.gbp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]
2026-09-13 - Swapped MCU for the STM32F405 series cause the F446 is out of stock for the foreseeable future
    [Flight Computer-B_Cu.gbl, Flight Computer-B_Mask.gbs, Flight Computer-B_Paste.gbp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]
2026-09-13 Generated code from CubeMX and fixed compiler errors
    [Code.ioc, main.cpp, main.h]
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

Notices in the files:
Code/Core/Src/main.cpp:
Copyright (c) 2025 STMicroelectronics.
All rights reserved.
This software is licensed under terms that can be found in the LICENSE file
